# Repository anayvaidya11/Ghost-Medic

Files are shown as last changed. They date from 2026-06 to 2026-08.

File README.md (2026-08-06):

# Archiater

*A **Wyzantium Industries** project. Formerly Ghost Medic; renamed 2026-08-05.*

**Offline decision-support software for the trained responder, running on the
device they already carry, with an optional wrist sensor accessory streaming
raw signals into it.** A local language model reasons about the patient, the
environment, and what the responder says, and speaks numbered candidate
actions. The responder on scene decides. No network, ever.

It is built for the places where help is hours away and there is no signal —
which is precisely where every other assistant stops working, because they all
assume a network. The gap it aims at sits between a satellite messenger, which
can reach help but cannot tell you what to do, and a printed
wilderness-medicine manual, which knows what to do but cannot see your
situation. (Why the product is software-first, and what that decision killed:
[`docs/POSITIONING.md`](docs/POSITIONING.md).)

The full system: 

```
  ┌───────────────────────┐                 ┌─────────────────────────────────┐
  │  1. WRIST SENSOR      │    JSON over    │  2. END-USER DEVICE             │
  │  ACCESSORY (optional) │ ── USB serial ─▶│  the responder's phone / laptop │──▶ responder
  │  RP2040 hub,          │   (raw signal + │  local LLM + voice + screen app │    decides
  │  3 sensors            │    environment) │  (React Native / Expo, Ollama)  │
  └───────────────────────┘                 └─────────────────────────────────┘
     firmware/                                 services/ + app/ (this repo)
```

## The parts

### 1. Wrist sensor accessory — optional hub  → [`firmware/`](firmware/)
A **Raspberry Pi Pico / RP2040** reading three I²C sensors on a shared bus:

| Sensor | Role |
|---|---|
| MAX30102 | Raw optical (PPG) front-end — raw red/IR counts, **not** HR/SpO₂ |
| BMP280 | Barometric pressure → altitude |
| LIS3DH | Accelerometer → motion / fall detection |

It samples at 10 Hz and streams one JSON object per line over USB serial. The
firmware is bare-metal C written against the Raspberry Pi Pico SDK. See
[`firmware/README.md`](firmware/README.md) for the driver details and, importantly,
the **honest validation status** (summarized below).

>  The firmware is **written and
> compile-tested against the real Raspberry Pi Pico SDK** It has
> **NOT yet been flashed or run on physical hardware**, and its readings have not
> been checked against real sensors. The drivers were transcribed carefully from
> the MAX30102, BMP280, LIS3DH datasheets, but transcription and timing bugs can
> only be caught on a bench, which hasn't happened yet. Treat it as a
> compile-verified design artifact. Full detail and
> the reasoning (including why no simulator run) is in
> [`firmware/README.md`](firmware/README.md).

### 2. The end-user device — app + local LLM  → [`services/`](services/)
The responder's own phone, EUD, or laptop, running a **local, off-the-shelf**
language model that consumes the sensor stream plus the responder's input and
produces decision support — all offline.

**This works today** (verified 2026-07-22): the app sends its prompt plus a
sensor-context block to `llama3.2:3b` running under Ollama on the same machine,
and the sensor state measurably changes the guidance — a fall flag adds head,
neck and spine assessment that the same question without it does not produce.
Evidence: [`docs/session-reports/2026-07-22-phase2-sensor-aware-llm.md`](docs/session-reports/2026-07-22-phase2-sensor-aware-llm.md).

**No dedicated compute unit will be built.** The end-user device is the
compute (decision 2026-08-05, [`docs/POSITIONING.md`](docs/POSITIONING.md)).
A laptop stands in for that device in the demo — and a laptop *is* an
end-user device, which is the point.

### 3. Interface — voice + screen app  → repo root (this repo)
The **React Native / Expo** app is the voice and screen surface the user actually
interacts with. It lives directly at the repository root rather than in a single
subfolder:

| Path | What's there |
|---|---|
| [`app/`](app/) | expo-router app — entry (`_layout.tsx`) + the UI (`index.tsx`) |
| [`services/`](services/) | LLM plumbing + forward-looking sensor/vision stubs |
| [`training/`](training/) | Fine-tuning pipeline — see [`training/README.md`](training/README.md) |

## Start here (project docs)

| Doc | What it's for |
|---|---|
| [`ROADMAP.md`](ROADMAP.md) | **Read first.** Phased plan + what's done vs. next. |
| [`ARCHITECTURE.md`](ARCHITECTURE.md) | System topology, what runs where, real-vs-simulated table. |
| [`DATA_FORMAT.md`](DATA_FORMAT.md) | The NDJSON wire contract between firmware, bridge, and app. |
| [`docs/POSITIONING.md`](docs/POSITIONING.md) | Why the product was repositioned 2026-08-05. Read this to understand the current framing. |

## Repository layout

```
Archiater/
├── README.md            ← you are here (whole-system overview)
├── ROADMAP.md · ARCHITECTURE.md · DATA_FORMAT.md   ← project memory
├── firmware/            ← 1. wrist sensor accessory — RP2040 hub (Pico SDK C)
│   └── README.md          firmware detail + validation status
├── simulator/           ← browser demo emitting firmware-format JSON (hardware-free)
├── app/                 ← 3. interface — React Native / Expo app (the entry)
├── services/            ← LLM + sensor/vision service layer
├── training/            ← wilderness-medicine fine-tuning pipeline
├── legacy/              ← archived deterministic TCCC app (not the product)
├── app.json, package.json, tsconfig.json, babel.config.js
└── ...
```

The **product is the offline decision-support software** (`app/` + `services/`). An earlier
deterministic TCCC/MARCH engine lives in [`legacy/`](legacy/README.md) — archived,
not deleted, and not imported by anything shipping.

## Data flow, in one sentence

The wrist accessory emits JSON sensor lines over USB serial → a serial→WebSocket
bridge forwards them to the app → the app pairs them with the responder's voice
input and the local LLM's reasoning to give offline decision support.

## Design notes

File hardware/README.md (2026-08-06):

# Archiater — Wrist-Unit PCB (hardware/)

KiCad **10.0.4** design for the Archiater wrist-unit sensor hub — the custom
board referenced throughout the docs. This is the real design source, committed so
the "custom PCB" claim is backed by files you can open, not just a screenshot.

> ## ⚠️ Honest status
> This board is **designed and routed in KiCad — not fabricated, not assembled,
> and not bench-tested.** No copy of this PCB physically exists yet. The firmware
> (`../firmware/`) is separately compile-verified against the Pico SDK but has also
> **never been run on this board.** Treat this as a verified *design artifact*: a
> complete schematic + routed 2-layer layout, with pin assignments that match the
> firmware — not a manufactured product.

## What's here

| File | What it is |
|---|---|
| `archiater-sensor-hub.kicad_sch` | Schematic (source of truth for the wiring) |
| `archiater-sensor-hub.kicad_pcb` | Routed board layout (35 footprints, ~477 track segments) |
| `archiater-sensor-hub.kicad_pro` | KiCad project file |
| `exports/archiater-sensor-hub-schematic.pdf` | Schematic, exported for viewing without KiCad |
| `exports/archiater-sensor-hub-3d-top.png` | 3D board render (KiCad 3D viewer, top) — the still fallback on the website |
| `exports/archiater-sensor-hub.glb` | 3D board model for the website's interactive viewer |
| `exports/archiater-sensor-hub-front-copper.svg` | Front copper layer as 2D artwork |

The `exports/` images are **generated from the source in this folder** — see
"Regenerating the images" below. They are the design's own tool output, not photos:
no physical board exists to photograph (see status above).

## The design

A single-board wrist unit: an RP2040 reading three I²C sensors, powered/programmed
over USB-C.

| Ref | Part | Role |
|---|---|---|
| U3 | RP2040 | MCU (bare-metal firmware, `../firmware/`) |
| U1 | W25Q128JVS | QSPI flash (firmware storage) |
| U2 | AMS1117-3.3 | 5 V (USB VBUS) → 3.3 V regulator |
| U4 | MAX30102 | **Raw optical (PPG) front-end — raw red/IR counts, not HR/SpO₂** |
| U6 | BMP280 | Barometric pressure / temperature → altitude |
| U5 | LIS3DH | 3-axis accelerometer → motion / fall detection |
| J1 | USB-C 2.0 (16P) | Power + data |
| Y1 | 12 MHz crystal | RP2040 clock |
| R6, R7 | 4.7 kΩ | I²C SDA/SCL pull-ups (shared bus) |
| SW1, SW2 | Push buttons | RUN / BOOT |
| D1 | LED | Status |

The three sensors share **one I²C bus** with a single pull-up pair (R6/R7) — the
same shared-bus topology described in `../README.md` and `../DATA_FORMAT.md`. The
MAX30102 label here matches the rest of the repo: it is a **raw optical front-end**,
and the firmware exposes raw red/IR counts, **not** a computed heart rate or SpO₂.

## Regenerating the exports

Everything in `exports/` is reproducible from the source in this folder with
KiCad 10.x. `kicad-cli` ships inside KiCad — on macOS it lives at
`/Applications/KiCad/KiCad.app/Contents/MacOS/kicad-cli`, which is not on `PATH`
by default:

```sh
KC=/Applications/KiCad/KiCad.app/Contents/MacOS/kicad-cli

# 1 — schematic PDF
$KC sch export pdf archiater-sensor-hub.kicad_sch \
  -o exports/archiater-sensor-hub-schematic.pdf

# 2 — still 3D render (the website's fallback when WebGL is unavailable)
$KC pcb render archiater-sensor-hub.kicad_pcb \
  -o exports/archiater-sensor-hub-3d-top.png --side top --quality high

# 3 — 3D model for the website's interactive viewer
$KC pcb export glb archiater-sensor-hub.kicad_pcb \
  -o exports/archiater-sensor-hub.glb --force \
  --include-silkscreen --include-soldermask

# 4 — front copper as 2D artwork (black on transparent)
$KC pcb export svg archiater-sensor-hub.kicad_pcb \
  -o exports/archiater-sensor-hub-front-copper.svg \
  --layers F.Cu,Edge.Cuts --mode-single --exclude-drawing-sheet \
  --fit-page-to-board --black-and-white
```

Then copy the four outputs into `../site/assets/`.

Or open `archiater-sensor-hub.kicad_pro` in KiCad and use **View → 3D Viewer**.

### Notes on those choices, so they aren't silently re-litigated

- **GLB, not VRML or STEP.** `kicad-cli` can emit all three; GLB is binary glTF,
  which three.js loads natively via `GLTFLoader` with materials intact and no
  conversion step.
- **Silkscreen and soldermask only — no `--include-tracks/-pads/-zones`.** Adding
  those triples the file (1.8 MB → 6.1 MB) and quadruples the draw calls for
  geometry you cannot see: the soldermask renders opaque, so the copper is hidden
  in the 3D view exactly as it is on a real board. Export 4 above is how the
  routing is actually shown.
- **One model is missing.** The MAX30102's package (`Maxim_OLGA-14_3.3x5.6mm_P0.8mm`)
  has no STEP model in the standard library, so U4 has no body in the render and
  `kicad-cli` prints `File not found:` for it. The part is present in the
  schematic and routed on the board; only its 3D shape is absent. The website
  says so rather than substituting a stand-in shape.

## Where this sits in the project

Hardware is **not** on the current critical path — see `../ROADMAP.md` (the wired
bridge stands in for the board today, and PCB *fabrication* is explicitly deferred).
This folder exists so the design work is visible and verifiable now.

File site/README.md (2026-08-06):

# Archiater proof website (`site/`)

A **static site with no build step**: five hand-written HTML pages, one shared
stylesheet, and one vendored library. Nothing to install, nothing to compile.
This follows [`../docs/WEBSITE_STRATEGY.md`](../docs/WEBSITE_STRATEGY.md) §5
(static-first, boring, maintainable) rather than a framework.

**Audience:** startup founders. Technical enough to smell exaggeration, often
not embedded engineers. So the prose translates rather than simplifies: it keeps
the specific number and the engineering reason and drops the jargon. Status is
stated on the overview page before anything is demonstrated, because saying it
first is what makes the rest believable.

**House style:** no em dashes and no figurative language in any prose, title, or
caption. Short, direct sentences. Verbatim artifacts (test output, model
transcripts, code, the sensor block) are exempt and must never be edited to fit
the style, because their whole value is being unedited.

## What's in here

| Path | What it is |
|---|---|
| `index.html` | **Overview**, the pitch, the honest status ledger, the concept viewer, the wire format explained |
| `how-it-works.html` | **How it works**, the four stages in plain language, with an animated 2D pipeline diagram |
| `hardware.html` | **Hardware**, the 3D board viewer, the copper routing, why each part is there |
| `proof.html` | **Proof**, test output, the recorded model transcript, the real-vs-simulated table |
| `about.html` | **About**, who built it, with links |
| `style.css` | The whole design system. Two devices carry the site: the *translation pair* (`.translate`) and the *ledger mark* (`.mark`) |
| `assets/board-viewer.js` | three.js board viewer, merges draw calls, falls back to the static render on any failure |
| `assets/product-viewer.js` | three.js concept illustration of how the system would be worn. Placeholder shapes built in code, labelled as concept, falls back to the inline 2D SVG. Two views: on the body, and the units alone |
| `assets/wearer-figure.js` | The cropped body form the concept is worn on. Also built in code: a lofted torso and a swept arm, not a scan and not CAD |
| `assets/app-demo.js` | Scripted replay of the app's screen. The response text is the verbatim recorded run; no model runs in the page |
| `assets/charts/*.svg` | Chart plates generated from the shipping code. See `../tools/charts/README.md` |
| `assets/*.glb / *.svg / *.png / *.pdf` | Generated from `../hardware/` source, see below |
| `vendor/three/` | three.js r185, MIT, vendored so the site has **zero external requests** |

Every factual claim on the site maps to a file in this repository, and the site
links out to each one.

## Regenerating the hardware assets

All four come from the committed KiCad source. `kicad-cli` ships inside KiCad
(on macOS: `/Applications/KiCad/KiCad.app/Contents/MacOS/kicad-cli`). Exact
commands live in [`../hardware/README.md`](../hardware/README.md); copy the
outputs here afterwards:

```sh
cp ../hardware/exports/archiater-sensor-hub.glb                assets/
cp ../hardware/exports/archiater-sensor-hub-front-copper.svg   assets/
cp ../hardware/exports/archiater-sensor-hub-3d-top.png         assets/
cp ../hardware/exports/archiater-sensor-hub-schematic.pdf      assets/
```

## Regenerating the charts

The three SVGs in `assets/charts/` are drawn from data produced by the shipping
C and TypeScript. Commands in [`../tools/charts/README.md`](../tools/charts/README.md).

## The stylesheet version query

Pages link `style.css?v=N`. Bump `N` whenever `style.css` changes, so cached
copies don't serve a stale design.

## Preview locally

```sh
cd site
python3 -m http.server 8090
# open http://localhost:8090
```

Use the local server, not a double-click. Opening `index.html` from `file://`
blocks JavaScript modules, so both 3D viewers fall back to their still image and
2D diagram. That is the fallback working as designed, but it is not a faithful
preview.

To iterate on the concept viewer on its own, serve the repository root instead
and open `tools/render/preview.html`. It mounts the same module with the camera
the site ships, and prints the measurements under the canvas.

## Deploy to Vercel, exact steps (no experience assumed)

1. Go to <https://vercel.com> → **Sign Up** → **Continue with GitHub** (the
   account that owns `Archiater`). The free "Hobby" plan is fine.
2. **Add New…** (top right) → **Project**.
3. Under "Import Git Repository," find **Archiater** → **Import**. (If it
   isn't listed, click "Adjust GitHub App Permissions" and grant access.)
4. On the configure screen, change exactly three things:
   - **Root Directory** → **Edit** → choose the **`site`** folder.
   - **Framework Preset** → **Other**.
   - **Build Command** → leave **empty**. **Output Directory** → leave as **`.`**.
5. **Deploy**. Under a minute later you get a URL like
   `archiater-xxxx.vercel.app`.
6. Every future `git push` to `main` redeploys automatically.

Custom domain later: Project → **Settings → Domains**.

## Updating the site

Edit the HTML, commit, push. That's the entire pipeline. The one rule worth
keeping: **if a claim can't be traced to a file in this repo, it doesn't go on
the site.**

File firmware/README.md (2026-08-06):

# Archiater — Sensor Hub Firmware (RP2040 / Raspberry Pi Pico)

Bare-metal C firmware for a Raspberry Pi Pico that reads three I²C sensors and
streams their data as JSON lines over USB serial. Part of the **Archiater**
project — an offline-first wilderness survival assistant. This firmware is the
"sensor hub" data source: it produces the biodata/environment stream that a
downstream host (and ultimately a local LLM) consumes.

## ⚠️ Validation status — read this first

This is a **portfolio / design artifact**. Be clear on exactly what has and has
not been verified:

| Claim | Status |
|---|---|
| Compiles against the real Raspberry Pi Pico SDK (C, `hardware/i2c.h`) | ✅ **Verified** — builds clean |
| Builds with **zero warnings** under `-Wall -Wextra` at `-O3` | ✅ **Verified** |
| Produces a flashable UF2 (`ghost_medic_firmware.uf2`, committed) | ✅ **Verified** (valid UF2 output) |

> **Why the committed file keeps its old name.** The tracked
> `ghost_medic_firmware.uf2` is the artifact of the verified build made under
> the project's former name, Ghost Medic. The rename touched no C source that
> reaches the chip, but no Pico SDK toolchain is available on this machine, so
> rebuilding is not possible and renaming the file in place would manufacture
> evidence of a build that never happened. The renamed target will produce
> `archiater_firmware.uf2` at the next real build, and this file will be
> replaced then.
| Drivers written directly against the MAX30102 / BMP280 / LIS3DH datasheets | ✅ True |
| **Flashed and run on physical hardware** | ❌ **NOT done** |
| **Verified against real sensors** (correct readings, timing, FIFO behavior) | ❌ **NOT done** |
| Run in the Wokwi RP2040 simulator | ❌ Not done — see below |

**In plain terms:** the code is proven to be well-formed, idiomatic Pico SDK C
that the compiler and linker accept and turn into a real firmware image. It is
**not** proven to behave correctly on a bench. Register addresses, config bit
patterns, and the Bosch compensation math were transcribed carefully from the
datasheets, but transcription errors, timing issues, and datasheet
misreadings can only be caught with hardware (a Pico + the three breakout
modules), which has not yet been done. Nothing here should be read as
hardware-validated.

### Why no Wokwi run?

The plan allowed ~30 minutes attempting a Wokwi RP2040 C-SDK simulation. This
was **not pursued**, for an honest reason: Wokwi's RP2040 sim does not cleanly
model these three specific parts (the MAX30102 optical front-end, the BMP280's
per-chip NVM calibration block, and the LIS3DH). Wiring up custom chip stubs
would have been simulator-plumbing work that validates the *stub*, not the
*driver* — it would produce a green checkmark that means nothing. The compile
verification above is a more truthful signal than a faked-sensor sim would be.
The right next validation step is real hardware, not a simulator.

## What it does

On boot it initializes I²C and all three sensors, then loops at 10 Hz. Each
tick it reads every sensor and prints one JSON object per line over USB serial,
for example:

```json
{"t_ms":1234,"max30102":{"ok":true,"red":10342,"ir":10501},"bmp280":{"ok":true,"temp_c":22.5,"press_pa":101010.2,"alt_m":25.7},"lis3dh":{"ok":true,"x_g":0.01,"y_g":-0.02,"z_g":0.99,"mag_g":0.99},"fall_detected":false}
```

If a sensor fails to initialize, the loop still runs and that sensor's object
reports `"ok":false` — one dead sensor doesn't take down the stream.

## Sensors

| Sensor | Role | I²C addr | Notes |
|---|---|---|---|
| MAX30102 | Raw optical (PPG) front-end  | `0x57` | Fixed address. Driver reads **raw RED/IR FIFO counts only** — no HR/SpO₂ algorithm (out of scope). |
| BMP280 | Barometric pressure → altitude | `0x76` | SDO→GND. Reads factory calibration, applies Bosch compensation formulas. |
| LIS3DH | Accelerometer / fall detection | `0x18` | SDO→GND. Includes an **illustrative** free-fall→impact heuristic (see below). |

Pin assignment (SDA = GPIO4, SCL = GPIO5) intentionally matches the custom
Archiater PCB so breadboard and board firmware are identical.

### Note on fall detection

`lis3dh_update_fall_detection()` implements the commonly-taught two-phase
pattern: a free-fall dip (total acceleration ≈ 0 g) followed within a short
window by a high-g impact spike. **It is a demonstration heuristic with
untuned textbook thresholds, not a validated or medical-grade algorithm.** A
real detector would use windowed signal features validated against labelled
fall data. It's included to show the data being *used*, and is labelled as
illustrative in the source.

### Note on altitude

Altitude uses the international barometric formula against a **fixed** sea-level
reference of 101325 Pa. Real absolute altitude needs the *local* sea-level
pressure (which drifts with weather), so treat the altitude figure as good for
*relative* changes, not survey-grade absolute elevation.

## I²C speed

The bus runs at **400 kHz (fast mode)**. All three parts support it, and short
breadboard wiring has no signal-integrity reason to run slower; the higher rate
leaves time headroom to service three devices inside each 100 ms tick. If long
or noisy wiring causes read failures, drop `I2C_BAUD` in `main.c` to `100000`.

## Files

```
i2c_helpers.h   Shared I²C read/write register helpers (Pico SDK wrappers)
max30102.c/.h   MAX30102 driver — raw RED/IR FIFO read
bmp280.c/.h     BMP280 driver — calibration + Bosch compensation + altitude
lis3dh.c/.h     LIS3DH driver — XYZ read + fall-detection heuristic
main.c          Bus + sensor init, 10 Hz read loop, JSON serial output
CMakeLists.txt  Standard Pico SDK build
```

Each driver exposes an `init()` and a `read()` returning a clean struct, and
keeps its register addresses and config constants named and commented against
the datasheet field they represent (not bare hex).

## Building

Requires the Raspberry Pi Pico SDK and an ARM cross toolchain
(`gcc-arm-none-eabi`, `cmake`). Copy `pico_sdk_import.cmake` from the SDK's
`external/` directory next to `CMakeLists.txt` (or set `PICO_SDK_PATH`).

```bash
mkdir build && cd build
cmake -DPICO_SDK_PATH=/path/to/pico-sdk ..
make
```

This produces `archiater_firmware.uf2` (the target was renamed 2026-08-05).
To flash: hold **BOOTSEL** while
plugging in the Pico, then drag the `.uf2` onto the `RPI-RP2` drive that
appears.

### Build environment this was verified in

- ARM GNU toolchain `arm-none-eabi-gcc` 13.2
- CMake 3.28
- Raspberry Pi Pico SDK (cloned from upstream `master`), TinyUSB submodule
- Target board: default `pico` (RP2040), stdio routed over USB CDC

Result: clean compile and link of all four source files, zero warnings under
`-Wall -Wextra`, valid UF2 generated.

## Consuming the output (downstream)

`stdio` is routed over **USB CDC serial** (not the UART pins). On a host, the
Pico appears as a serial device (`/dev/ttyACM0`, `/dev/tty.usbmodem…`, or a
`COM` port). Each line is a complete JSON object. In the Archiater system a
small serial→WebSocket bridge forwards these lines to the React Native app —
the wired stand-in for the eventual wrist→pack BLE link (the Pico has no radio).

## Known limitations / honest TODO

- Not run on hardware; no reading has been checked against a reference.
- MAX30102 reads one sample per tick rather than draining the full FIFO — fine
  for a demo stream, insufficient for real PPG signal processing.
- No HR/SpO₂ computation (raw counts only).
- Fall-detection thresholds are untuned placeholders.
- No I²C error recovery/retry beyond per-read `ok:false` reporting.
- Altitude uses a fixed sea-level reference.

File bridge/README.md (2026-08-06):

# Archiater — Sensor Bridge

> ## ⚠️ What this is, stated honestly
> This bridge is a **wired, local WebSocket stand-in for the eventual
> wrist→pack _BLE_ link.** It is **not** BLE. It is **not** wireless. Nothing in
> this folder has run on physical hardware. It exists so the rest of the system
> (simulator → app → LLM) can be built and demonstrated **today, hardware-free**,
> and so that swapping in a real flashed Pico later changes only the data
> *source*, not the app. Do not read "bridge" as "the radio link works."

## What it does

A **dumb pipe.** It reads NDJSON telemetry lines from a *source* and forwards
each line **unchanged** to every connected *consumer* (the app, or a test client)
over a WebSocket.

```
  producers                         BRIDGE (this program)                 consumers
  ─────────                         ─────────────────────                 ─────────
  simulator ──ws /sim-input──▶   ┌────────────────────────┐   ──ws /stream──▶  app
  file replay ──────────────▶    │  drop lines w/o "t_ms"  │   ──ws /stream──▶  test-client
  serial (later) ───────────▶    │  forward the rest AS-IS │
                                 └────────────────────────┘
```

The bridge performs exactly **one** transformation, per
[`../DATA_FORMAT.md`](../DATA_FORMAT.md): it **drops any line that lacks a
`t_ms` field** (this silently drops the firmware's one-time boot line, and any
blank/garbage line). It does **not** parse-and-rebuild, reshape, or validate any
other field. Lines that pass the filter are forwarded byte-for-byte as received.

## Install

```sh
cd bridge
npm install        # installs 'ws' only
```

`serialport` is intentionally **not** a dependency yet — it will be added only
when `--source=serial` is actually implemented, to keep the dependency list
honest about what works.

## Run

**File mode** — replay captured lines at ~10 Hz (no browser, fully deterministic):

```sh
node bridge.js --source=file --file=sample.ndjson
```

**Sim mode** — accept live lines pushed by the browser simulator:

```sh
node bridge.js --source=sim
# then open ../simulator/index.html?bridge=1 in a browser and press Start
```

> The `?bridge=1` is required: the simulator only connects to the bridge when
> that flag is present. Opened plainly (no flag) it stays fully standalone and
> makes no network calls — so it never errors when the bridge isn't running.

**Serial mode** — reserved, not implemented:

```sh
node bridge.js --source=serial   # exits with a clear "not implemented" message
```

Options: `--port=8080` (default), `--hz=10` (file replay rate), `--loop`
(file mode only — replay the file from the top forever, for continuous app
testing without hardware; without it, file mode stops after one pass).

## Endpoints

| Path | Who connects | Direction |
|---|---|---|
| `ws://localhost:8080/stream` | the app / `test-client.js` | bridge → consumer (receive lines) |
| `ws://localhost:8080/sim-input` | the simulator | producer → bridge (push lines) |

## Test it (hardware-free)

Terminal 1:

```sh
node bridge.js --source=file --file=sample.ndjson
```

Terminal 2:

```sh
node test-client.js
```

`sample.ndjson` contains 5 non-empty lines: **1 boot line (no `t_ms`)** and
**4 data lines**. The test client should therefore receive **4** lines — proving
the boot line was dropped and everything else forwarded unchanged.

## Adding real hardware later (the seam)

`--source=serial` is stubbed on purpose. When a real Pico is flashed
(Phase 3 in [`../ROADMAP.md`](../ROADMAP.md)), implementing it means: open the
serial port, read newline-delimited lines, and call the **same** internal
`forward()` path that file and sim modes use. No consumer-side change, no
restructuring — that is the whole point of the producer/consumer split.

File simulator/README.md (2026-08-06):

# Archiater — Wrist Unit Simulator

A single-file, self-contained web page that **simulates** the Archiater wrist
sensor hub. Open `index.html` by double-clicking it — no server, no build step,
no internet, no dependencies.

## What this is (and is NOT)

- ✅ It **is** a demonstration of the Archiater data pipeline. You drag three
  sliders, physically-plausible sensor values are computed, and a live JSON
  stream scrolls past — the exact same JSON shape the real firmware prints.
- ❌ It is **NOT** reading any real hardware. There are no sensors attached.
  Nothing here talks to a Pico. The values are generated in your browser.

The page says this loudly in its header, on purpose. This is a simulator standing
in for the wrist unit.

## Why it's still faithful

Every formula and threshold in the simulator is copied straight from the real
firmware in this repo, so the numbers behave the way the actual device would:

| What | Simulator source | Firmware source |
|---|---|---|
| Altitude → barometric pressure | inverse of the barometric formula | `firmware/bmp280.c` (`SEA_LEVEL_PA`, exponent `0.1903`, coeff `44330`) |
| Temperature | 15 °C at sea level, −6.5 °C per 1000 m | standard-atmosphere lapse rate |
| Fall detection | free-fall < 0.35 g **then** impact > 2.5 g within 400 ms | `firmware/lis3dh.c` (`FREEFALL_THRESHOLD_G`, `IMPACT_THRESHOLD_G`, `FALL_IMPACT_WINDOW_MS`) |
| Raw IR/RED counts | large baseline integers + small pulsing waveform | `firmware/max30102.c` (raw 18-bit FIFO counts, **not** a real HR algorithm) |
| Loop rate | 10 Hz (one JSON line per 100 ms) | `firmware/main.c` (`LOOP_PERIOD_MS`) |

The **"Simulate Fall"** button scripts the real two-phase signature the firmware
looks for — a brief near-0 g free-fall dip followed by a high-g impact spike —
and runs the *same* detection code the RP2040 runs. When both phases land inside
the 400 ms window, the page raises a **FALL DETECTED** alert, exactly as the
firmware would flip `"fall_detected":true`.

## The JSON is the contract

The stream emits one object per line, matching the firmware byte-for-byte in
field order and number precision:

```json
{"t_ms":1234,"max30102":{"ok":true,"red":10342,"ir":10501},"bmp280":{"ok":true,"temp_c":22.5,"press_pa":101010.2,"alt_m":25.7},"lis3dh":{"ok":true,"x_g":0.01,"y_g":-0.02,"z_g":0.99,"mag_g":0.99},"fall_detected":false}
```

Because the shape is identical, **a real wired Pico can replace this simulated
source with zero downstream changes.** Anything that consumes the stream — the
app, an LLM, a serial→WebSocket bridge — cannot tell whether the line came from
this page or from a physical wrist unit. That's the whole point: prove and demo
the pipeline now, swap in real hardware later without touching the consumer side.

## How to open it

Double-click `simulator/index.html`, or drag it into any modern browser
(Chrome, Safari, Firefox, Edge). It runs entirely offline.

## Controls

- **Altitude (0–4000 m)** — sets BMP280 pressure and temperature.
- **Motion / g-force (0–4 g)** — drives the accelerometer magnitude.
  **Simulate Fall** scripts the free-fall→impact sequence.
- **Exertion (0–100)** — drives an internal pulse model that shapes the raw
  IR/RED optical counts. The pulse rate itself is never displayed or emitted —
  the device outputs raw counts, not heart rate.
- **Temp offset (−40..+20 °C)** — shifts the emitted BMP280 temperature on top
  of the altitude lapse rate (cold-snap / heat demos).
- **Sensor failures** — per-sensor checkboxes emit `{"ok":false}` with numeric
  fields omitted (per `DATA_FORMAT.md`), to exercise the consumer's failure path.
- **Pause / Clear** — freeze the stream or wipe the log.

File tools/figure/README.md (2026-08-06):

# tools/figure — where the mannequin comes from

`site/assets/wearer-body.glb`, the figure the product concept is worn on, is
built from MakeHuman's base mesh. This file records the source, the license,
and the exact commands, so the artifact maps to a documented pipeline the
same way the chart plates and the board GLB do. Nothing here ships with the
site and nothing is added to `package.json`; the two converters run under
`npx` on the dev machine only.

## Source and license

- **Source:** `base.obj` from the MakeHuman project,
  <https://raw.githubusercontent.com/makehumancommunity/makehuman/master/makehuman/data/3dobjs/base.obj>
  (retrieved 2026-08-05, 1,749,303 bytes, 19,158 vertices / 18,486 quads).
- **License: CC0 1.0.** Declared in the file's own header:

  > This asset was explicitly released as CC0 in september 2020. ...
  > The copyright holders at the point of the release to CC0 were:
  > Copyright (C) 2020 Data Collection AB, https://www.datacollection.se
  > Copyright (C) 2020 Joel Palmius
  > Copyright (C) 2020 Jonas Hauquier

  The MakeHuman application is GPL; its LICENSE materials state plainly that
  the license of exported assets is not affected. The mesh itself is CC0, so
  no attribution is required. Credit given anyway: the figure is the
  MakeHuman `hm08` base mesh.
- **What it is on the page:** a generic open-source base mesh rendered as a
  matte studio mannequin. It is not a scan of anyone and it is nobody's real
  proportions. The site says the same wherever the figure appears.

## The pipeline (run 2026-08-05)

```sh
curl -sLO https://raw.githubusercontent.com/makehumancommunity/makehuman/master/makehuman/data/3dobjs/base.obj

# 1 — keep only the `body` group. The source is one mesh in 172 groups:
#     the body, MakeHuman's helper-* clothing shells, and ~100 tiny joint-*
#     rigging cubes. Face indices are global, so the script renumbers them.
node tools/figure/extract-body.mjs base.obj body.obj
#   kept: body, 13,378 faces, 13,380 of 19,158 vertices referenced
#   dropped: 5,108 faces across 138 other groups

# 2 — OBJ to binary glTF
npx --yes obj2gltf@3 -i body.obj -o body-raw.glb --binary       # 452,280 B

# 3 — optimize for the web. Quantization only, no simplification: the full
#     13.4k quads keep the hands and face silhouette clean, and the file is
#     small anyway. KHR_mesh_quantization decodes natively in the vendored
#     three.js r185 GLTFLoader, so no decoder file has to ship.
npx --yes @gltf-transform/cli@4 optimize body-raw.glb wearer-body.glb \
  --compress quantize --simplify false --texture-compress false   # 268,640 B

cp wearer-body.glb ../site/assets/wearer-body.glb
```

A simplified variant (`--simplify true --simplify-ratio 0.6`) measured
161,616 bytes and was rejected: 107 KB was not worth the silhouette loss on
the one figure the page is about. For scale, the board GLB is 1.77 MB.

## Notes

- The source OBJ has no normals; the loader computes smooth vertex normals
  after merge (`site/assets/wearer-figure.js`).
- `--eyes` on the extract script also keeps MakeHuman's eyeball shells, in
  case the empty sockets read as holes in a render. The shipped build keeps
  only the body group; rebuild with `--eyes` if a render shows holes.

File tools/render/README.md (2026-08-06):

# tools/render — looking at the 3D concept viewer

Development tools. Nothing here ships with the site, and nothing here is a
project dependency: no entry is added to `package.json` and no package is
installed. `shot.mjs` talks to a browser that is already on the machine using
Node's built-in `WebSocket`.

## Why this exists

`site/assets/product-viewer.js` and `site/assets/wearer-figure.js` build their
geometry in code. Numbers can be checked headlessly, and are: the preview page
prints clearances, gaps and marker positions under the canvas. But a bounding box
cannot tell you whether an arm reads as an arm, so there has to be a way to
actually look at the thing while changing it.

The measurements are the point as much as the pictures. An early version of the
figure mounted the wrist band in a place that measured fine and looked wrong; a
later one had a cable that passed through the hand. Both were found by looking.
Both are now numbers the preview prints, so they cannot come back silently.

## preview.html

Mounts the same viewer module the site uses, on its own, with the camera the site
ships. Serve the **repository root**, not `site/`:

```sh
python3 -m http.server 8932
# then open:
#   http://localhost:8932/tools/render/preview.html            on the body
#   http://localhost:8932/tools/render/preview.html?wearer=0   the devices alone
```

`?devices=` picks the device set (`wrist+phone`, the shipped one, or the
harness-only `wrist+pack` / `wrist+phone+pack`). `?preset=` picks a camera
preset without clicking: `figure`, `wrist`, `phone`, `pack`, `all`.

The page never auto-rotates, so two screenshots of the same code are identical.

Printed under the canvas (the figure loads from a GLB, so the page waits for
the viewer's `ready` promise before measuring):

| Line | What it is guarding |
|---|---|
| `stature / scale applied / flipped` | The GLB's own units and facing are never trusted; this reports what normalisation actually did. The facing probe once flipped the figure backwards. |
| `wrist max radius` and `band radial margin` | The band's bore is sized to the measured wrist. A negative margin means the band is sunk into the skin. The wrist scan once landed in the palm and reported 45 mm. |
| `pack seat radius` | The (killed) pack's inner face is a 150 mm arc; the seat is wherever the measured torso curvature comes closest. |
| `chest surface z` | Where the chest mount's plate meets the measured torso. |
| `cable to torso gap` | Negative means the cable runs through the wearer. |
| `cable to arm gap` | Negative means the cable runs through the limb it is routed beside. It did once. |
| `cable slack` | A cable is longer than the gap it spans. Near 0% means it is drawn as a taut rod. |
| `marker N at` | Pixel position on the canvas, and the distance to the nearest other marker. Placing these by eye costs a screenshot per nudge. |

## shot.mjs

```sh
node shot.mjs <url> <out.png> [waitMs] [width] [height] [clipSelector] [clickSelector]
```

```sh
# the concept as the site renders it
node shot.mjs http://localhost:8932/tools/render/preview.html out.png 6500 1280 900 "#product-viewer"

# the site's own page, after clicking through to the other view
node shot.mjs http://localhost:8933/index.html out.png 5000 1280 900 "#product-viewer" 'button[data-view="units"]'
```

`waitMs` has to cover the WebGL scene settling; 5000 to 7000 is reliable with
software rendering. Page exceptions are printed to stderr, so a silent JavaScript
failure does not pass as a good screenshot.

Set `CHROME_PATH` if the browser is not in one of the usual places.

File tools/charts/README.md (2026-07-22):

# Chart pipeline (`tools/charts/`)

Generates the three chart plates in `site/assets/charts/`. The rule that makes
them trustworthy: **the data comes from the shipping code, and this folder only
draws it.**

| Output | Data source |
|---|---|
| `fall-signature.svg` | `trace_driver.c`, which links the firmware's own `fall_detection.c`. The motion trace is synthetic; every flag decision is the real state machine. |
| `altitude-curve.svg` | Same driver, sweeping `bmp280_pressure_to_altitude()` from the firmware's own `bmp280_compensation.c`. |
| `debounce.svg` | `debounce_data.mjs`, which imports the app's real `services/fallTrigger.ts` and replays 60 s of the demo fall loop: 2 calls instead of 150. |

The intermediate CSVs are committed so the SVGs can be checked against their
data without rebuilding anything.

## Regenerating

```sh
cd tools/charts

# 1. data from the shipping C
gcc -Wall -Wextra -std=c11 -I../../firmware trace_driver.c \
    ../../firmware/fall_detection.c ../../firmware/bmp280_compensation.c \
    -lm -o trace_driver && ./trace_driver

# 2. data from the shipping TypeScript (Node >= 22.6)
node --disable-warning=MODULE_TYPELESS_PACKAGE_JSON debounce_data.mjs

# 3. draw (any venv with matplotlib; not a project dependency)
python3 -m venv /tmp/chartsenv && /tmp/chartsenv/bin/pip install matplotlib
/tmp/chartsenv/bin/python make_charts.py
```

matplotlib is a build-time tool on the developer machine only. Nothing in the
site or the app depends on it; the site ships static SVGs with text as paths,
so they render identically with no fonts installed.

Style notes: single green data series (`#55884D`, validated for lightness,
chroma and contrast against the site's paper surface), gray reference lines,
clay reserved for the one status mark (the fall flag). Transparent background
so the plate sits on the site's paper panel.

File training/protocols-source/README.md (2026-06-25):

# Grounding Documents

Paste your source material here as plain-text (`.txt`) files. The dataset
generator (`../generateDataset.ts`) reads every `.txt` file in this folder and
folds the combined text into its prompts so synthetic answers stay anchored to
real doctrine rather than the model's unverified recall.

## What to put here

- **Wilderness Medical Society (WMS) practice guidelines** — e.g. the
  guidelines for hypothermia, frostbite, heat illness, acute altitude illness,
  anaphylaxis, lightning injuries, and spine assessment in the wilderness.
- **NOLS Wilderness Medicine** textbook excerpts — Patient Assessment System
  (PAS), the ABCDE primary survey, the SAMPLE secondary survey, and evacuation
  guidelines.
- **CDC wilderness / travel health references** — environmental exposure,
  waterborne illness, venomous bites and stings.

## Format guidance

- Plain UTF-8 text, one topic per file is fine (e.g. `wms-hypothermia.txt`).
- Strip page headers/footers and figure captions where you can — clean prose
  grounds the model better.
- Keep excerpts reasonably short; very long files are truncated by the
  generator to fit the prompt budget (see `MAX_GROUNDING_CHARS` in
  `../generateDataset.ts`).

## Copyright

These documents are used **locally** to ground synthetic data generation. Make
sure you have the right to use any copyrighted material this way, and do not
commit licensed text to a public repository. This folder is a drop point on your
own machine; only this README is tracked by default.

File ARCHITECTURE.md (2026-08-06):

# Archiater — Architecture

*What the system is, what runs where, and exactly where the "real" line is.*

Archiater (a **Wyzantium Industries** project, formerly Ghost Medic) is an
**offline decision-support prototype**: a trained responder — a medic, an
expedition leader, a remote-site lead — is treating a patient far from help,
with no signal. The system senses the patient and the environment, reasons
about it with a **local** language model, and speaks numbered candidate
actions for the responder to weigh — with **no internet**. The responder on
scene decides.

## The one product (decided 2026-07-20, repositioned 2026-08-05)

The product is **offline decision-support software running on the device the
responder already carries**, with the wrist sensor hub as an optional
accessory (`app/` + `services/`; rationale in
[`docs/POSITIONING.md`](docs/POSITIONING.md)). An earlier deterministic
TCCC/MARCH engine was archived to [`legacy/`](legacy/README.md); it is not
part of this architecture.

## System topology — what runs where

Three roles plus the human. In the **shipping vision** the end-user device is
the responder's own phone or EUD; in the **current demo** a laptop plays that
device. Being explicit about this is the whole point — it's how we stay honest
about what's proven.

```
 ┌────────────────────────┐            ┌─────────────────────────────────────┐
 │  WRIST SENSOR          │            │  END-USER DEVICE                    │
 │  ACCESSORY (optional)  │  THE LINK  │  (the phone / EUD / laptop the      │
 │                        │──────────▶ │   responder already carries)        │──▶ trained
 │  RP2040 + MAX30102 raw │  NDJSON    │                                     │    responder
 │  PPG + BMP280 baro +   │  over the  │  app (Expo) + local LLM (Ollama)    │    decides
 │  LIS3DH accel          │  bridge    │  + vision/voice stubs               │
 │  emits NDJSON @ 10 Hz  │            │  decision support, fully offline    │
 └────────────────────────┘            └─────────────────────────────────────┘

                    ══════════ THE BRIDGE ══════════
                    NDJSON source → WebSocket server
                    (stand-in for the eventual short-range wireless link)
```

### Role by role

| Role | Shipping vision | Demo today | Status |
|---|---|---|---|
| **Wrist sensor accessory** (optional) | Custom PCB: RP2040 + MAX30102 + BMP280 + LIS3DH | Same firmware, run on a Pico *or* replayed by the bridge | 🟢 Firmware built & compile-verified; ⚠️ not yet run on hardware |
| **The link** | Wrist → device short-range wireless (BLE) | Node WebSocket server, `--source ∈ {serial,sim,file}` | 🟢 Works in `file` mode (verified end-to-end); `serial` stubbed pending hardware |
| **End-user device** | The responder's phone / EUD, running the app and a local LLM | **Laptop** running the app in a browser and Ollama | 🟢 Works — and note the demo device *is* an end-user device, which is the point |

The pack-compute question is not deferred, it is **closed** (2026-08-05, see
[`docs/POSITIONING.md`](docs/POSITIONING.md)): the end-user device is the
compute. No dedicated carried computer will be chosen or built.

*The earlier four-role topology (with a dedicated "pack brain") is in git
history and analyzed in `docs/POSITIONING.md`.*

## Data flow (the contract-first design)

```
sensors → firmware → NDJSON line → bridge → WebSocket → app → LLM prompt → spoken advice
```

The load-bearing idea: **one JSON line format is the contract between every stage**
(see [`DATA_FORMAT.md`](DATA_FORMAT.md)). Because the shape is identical whether a
line came from a real Pico, the browser simulator, or a replayed capture, any
producer can be swapped for any other **without touching the consumer**. That is
what lets us prove the whole pipeline today, hardware-free, and swap in the real
wrist unit later by changing one flag.

## The three data sources (same format, increasing realism)

1. **`simulator/index.html`** — a browser page with sliders. A standalone *visual
   demo* you open yourself. Not in the app's data path, and **no longer embedded
   in the site** (removed from the overview page 25 Jul 2026, along with the
   byte-identical copy that used to live at `site/simulator/`).
2. **The bridge's `sim`/`file` modes** — replays/generates NDJSON at 10 Hz for the
   hardware-free app demo. The honest goal: generate it from the firmware's *own*
   pure C math (`firmware/bmp280_compensation.c`, `firmware/fall_detection.c`) so
   the test stream is the shipping code, not a reimplementation.
3. **A real flashed Pico** — `--source=serial`. The truth. Gated on hardware.

## What is real vs. simulated (read this honestly)

| Claim | Real? |
|---|---|
| Firmware compiles against the real Pico SDK, zero warnings, valid `.uf2` | ✅ Verified |
| Firmware sensor math (BMP280 compensation, fall detection) is unit-tested | ✅ Verified (host tests pass) |
| PCB designed & routed (RP2040 + 3 sensors, KiCad) — source in [`hardware/`](hardware/) | ✅ Real design (not fabricated/assembled) |
| Firmware run on physical hardware / real sensors | ❌ Not yet |
| App → local LLM → spoken numbered advice | ✅ Works (Ollama) |
| Live sensor data actually driving the app | ✅ Verified 2026-07-22 (bridge replay → browser app; connection observed server-side) |
| Sensor readings influencing the LLM's advice | ✅ Verified 2026-07-22 (sensor-context injection; fall auto-trigger fired once per 30 s cooldown against live local Ollama) |
| BLE wrist→device link | ❌ Simulated by the wired bridge (on purpose) |
| Speech-to-text, wound vision | ❌ Stubs (`services/transcriptionService.ts`, `services/visionService.ts`) |
| Runs on a dedicated carried computer | ❌ Killed by design (2026-08-05) — the end-user device is the compute; a laptop is the end-user device in the demo |

See [`ROADMAP.md`](ROADMAP.md) for the sequence that turns the 🔜/❌ rows green.

## Phase 2 — Sensor-Aware LLM  ✅ BUILT (2026-07-22)

*How live wrist telemetry reaches the model's reasoning. This section was written
as a design proposal and **is now implemented** — the design below was followed,
so it doubles as the module's documentation:*

- `services/sensorContext.ts` builds the delimited block (16 committed tests).
- `services/fallTrigger.ts` implements the rising-edge auto-trigger (12 tests).
- Both are wired into `app/index.tsx`; the exact block sent is viewable in the UI.
- Run the tests with `npm test` (39 total, no dependencies — see `tests/README.md`).
- Verified against live local Ollama: `docs/session-reports/2026-07-22-phase2-sensor-aware-llm.md`.

### Where it plugs in today
`services/llmService.ts` makes one call to Ollama `/api/generate` with:
- a **system** prompt (`WILDERNESS_SYSTEM_PROMPT`) — persona + wilderness-medicine
  doctrine (PAS / ABCDE / WMS), ≤6 one-sentence steps, mandatory EVACUATION line;
- a **user** prompt — `SITUATION REPORT:\n<patientReport>\n\nGive … steps now:`.

(Note: the app *simulates* token streaming — the model is called with
`stream:false` and the full text is replayed word-by-word. Real token streaming is
a separate later task.)

The snapshot already exists in the UI: `useWristVitals()` runs at the top of
`app/index.tsx`, so the latest `WristVitals` is in hand at submit time — **no new
plumbing needed to obtain it.**

### The injection point (simplest honest version)
Attach the **latest vitals snapshot at the moment of submit**, into the **user**
prompt (not the system prompt), as a clearly-fenced context block:

```
CURRENT SENSOR READINGS (wrist unit, live):
  Altitude: 2.1 m (relative)     Temperature: 21.0 °C (ambient)
  Fall detected: YES
  [raw signal — NOT vitals] optical red: 10249  ir: 10398   accel: 2.62 g
```

Rules that keep it honest:
- **Gate on `ok`.** Omit any field whose sensor reported `ok:false`; write
  `unavailable`, never a fabricated number or a `0`.
- **Label raw as raw.** Optical red/ir and accel magnitude are raw counts, passed
  through labeled "NOT vitals."
- **Forbid derivation the firmware didn't do.** The system prompt must explicitly
  instruct the model: *do not infer heart rate, SpO2, or pulse from the raw optical
  counts — that computation is not performed.* Without this, a model will happily
  invent a BPM. This is the load-bearing honesty guardrail of Phase 2.
- **Altitude is relative** (fixed 101325 Pa sea-level ref, per `DATA_FORMAT.md`) and
  temperature is **ambient**, not body temperature — say both in the block.

### System-prompt amendment (how to reason about the readings)
Add a short interpretation guide to `WILDERNESS_SYSTEM_PROMPT`:
- **Altitude** → weigh altitude-illness risk (AMS / HACE / HAPE) as elevation and
  ascent rate rise.
- **Temperature (ambient)** → near/below freezing raises hypothermia / frostbite
  risk; high temp raises heat-illness risk.
- **Fall detected = YES** → treat as possible fall trauma: spinal precaution,
  head- and internal-injury vigilance — weighed against the user's own report.
- **Raw optical / accel** → context only; explicitly *not* a vital sign.

### Trigger model
- **On user submit:** attach the current snapshot (above). Zero extra cadence.
- **On a fresh `fall_detected` rising edge (optional — the demo moment):**
  auto-compose a submit ("possible fall detected — <snapshot>") so a fall
  *visibly changes the advice* with no typing. This satisfies Phase 2's DONE-WHEN.
- A periodic "every N seconds" re-query is **not** proposed — it burns model calls,
  and the readings only matter at decision time.

### DONE WHEN (per ROADMAP)
A fall event or an abnormal vital *visibly changes* the model's guidance, with the
raw-vs-derived and "no HR/SpO2" labels intact in the injected context.

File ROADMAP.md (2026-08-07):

# Archiater — Roadmap

**Read this first, every session.** It exists so you never have to hold the whole
project in your head again. Pick the lowest unchecked phase, do it, check it off.

- **Product (decided 2026-07-20):** the **LLM wilderness assistant** (`app/` +
  `services/`). The old deterministic TCCC engine is archived in [`legacy/`](legacy/README.md).
- **What we're optimizing for:** *Goal B* — a highly technical, honest **proof**
  that the engineering works (simulation + real firmware link + docs), shown on a
  Vercel site + this repo. Not a hardware-validated medical device (that's Goal A,
  years away). For a proof, a **demonstrated, honestly-labeled** end-to-end pipeline
  beats a half-finished "real" one.
- **North star:** *one command brings up sensor stream (from the firmware's own
  math, no hardware) → bridge → app → local LLM → spoken triage advice, fully
  offline, every real-vs-simulated boundary labeled — plus one video of the Pico
  streaming on real hardware.*

See [`ARCHITECTURE.md`](ARCHITECTURE.md) for topology and [`DATA_FORMAT.md`](DATA_FORMAT.md)
for the wire contract.

---

## Locked Decisions (confirmed by owner — do not relitigate)

> **Repositioning 2026-08-05 (supersedes decision 1's framing; see
> [`docs/POSITIONING.md`](docs/POSITIONING.md)).** The product is **Archiater**
> (company: **Wyzantium Industries**): offline decision-support software for a
> trained responder, running on the device they already carry (phone / EUD /
> laptop), with the wrist sensor hub as an **optional accessory** streaming raw
> signals into it. The belt pack is killed, not deferred. The guidance posture
> is decision support, never directives to a layperson. Decision 1 below is
> kept as written because the history of the change is part of the record.

1. **What it is:** an offline, wearable AI **first-aid assistant prototype**. A
   wrist-worn sensor hub captures motion, altitude/environment, and raw optical
   signals, streams them to a **local (no-internet) LLM** that combines them with
   voice + image input to speak numbered first-aid guidance.
2. **What the app shows:** altitude, temperature, and fall-status as
   honestly-derived values; raw optical (red/IR) and acceleration as
   clearly-labeled **raw signal** (live trace). **No heart-rate / SpO2 / BPM number
   anywhere.** Raw vs. derived is visually distinguished.
3. **What the site proves:** a full offline pipeline (firmware-grade sensor data →
   bridge → app → local LLM → spoken advice) runs end-to-end and *responds to its
   inputs*, with every real-vs-simulated boundary labeled. The physical-hardware
   run is shown separately as a scoped video artifact.
4. **Build order:** Phase 1 bridge+app → Phase 2 sensor-changes-advice →
   Phase 3 hardware video → Phase 4 website.

### Out of scope (committed — do NOT build)
- No HR / SpO2 / BPM computation.
- No real BLE — the wired local WebSocket bridge is the honest stand-in.
- No dedicated "pack" hardware — **laptop = pack**; the topology is a documented
  tradeoff study, not a device to build now.
- No real speech-to-text or wound vision — both are **stubs**.
- No PCB fabrication.
- No medical-validity claims.

---

## Status legend
🟢 done · 🟡 in progress · ⬜ not started · 🧊 deferred (don't do yet)

---

## Phase 0 — Kill the ambiguity  🟢 DONE (2026-07-21)
*One product, one repo, shared memory.*
- 🟢 Decision made: product = LLM wilderness assistant.
- 🟢 TCCC engine archived to `legacy/` (product typechecks clean; nothing imports legacy).
- 🟢 `ARCHITECTURE.md`, `DATA_FORMAT.md`, this `ROADMAP.md` written.
- 🟢 `simulator/` committed.

## Phase 1 — The spine (the bridge)  🟡 IN PROGRESS
*Make sensor data actually reach the app. Highest leverage.*
- 🟢 Node bridge: reads NDJSON, re-broadcasts unchanged over `ws://localhost:8080`.
  `--source ∈ {serial, sim, file}`; `file` mode shipped (+ `--loop` for continuous
  replay), `serial` stubbed with a clear message. Drops lines without `t_ms`.
  Dep: `ws` only. Verified: `test-client.js` receives the 4 data lines, boot line
  dropped, loops correctly. (`bridge/`, spec in `DATA_FORMAT.md`.)
- 🟢 App wired to `ws://localhost:8080/stream`: `services/useWristVitals.ts` +
  `services/wristVitalsParser.ts` parse NDJSON per `DATA_FORMAT.md` (every field
  gated on its `ok` flag), consumed by `app/index.tsx`'s `VitalsMonitor` on the
  READY screen with a ●LIVE/○DISCONNECTED indicator. Honest: raw vs. derived split,
  nulls render "—", no HR/SpO2. Verified: `npx tsc --noEmit` clean; the compiled
  parser maps the live bridge stream to correct values (incl. `ok:false` → "—").
  *Not yet verified: React actually painting the values in a running browser.*
- ⬜ **Upgrade the `sim` source** to generate the stream from the firmware's *own*
  pure C (`firmware/bmp280_compensation.c`, `firmware/fall_detection.c`) compiled
  on the host — so the test data is the shipping code, not a reimplementation.
- **DONE WHEN:** replayed/generated sensor lines make the numbers in the app move, live.

## Phase 2 — Close the loop  🟡 NEARLY DONE (2026-07-22)
*Sensor data changes the AI's answer.*
- 🟢 Sensor context injection: `services/sensorContext.ts` (pure, 16/16 headless
  tests) builds a delimited block — derived values qualified (altitude relative,
  temp ambient-not-body), raw optical labeled non-diagnostic, `ok:false` →
  "unavailable" never 0, disconnected → honest "no sensor data". Appended to
  every LLM request in `app/index.tsx`; the exact sent block is viewable in the
  UI ("SENSOR CONTEXT ATTACHED" chip). System prompt extended with reasoning
  rules incl. NEVER inferring HR/SpO2 from raw counts.
- 🟢 Fall auto-trigger: `services/fallTrigger.ts` (rising edge + 30 s cooldown +
  suppression; 6/6 headless tests — 1 fire per replay loop, not 4). Auto-submits
  post-fall guidance, labeled "SENSOR-TRIGGERED (not typed by user)"; toggleable.
- 🟢 Simulator upgraded as demo instrument: temp-offset + per-sensor `ok:false`
  failure toggles (headless-verified against the app parser); bpm display
  removed (Decision 2).
- 🟢 **DONE-WHEN evidence:** real Ollama (llama3.2:3b, local) called with the
  app's exact payload construction — the fall-context response adds head/neck/
  spine + hidden-trauma assessment absent from the no-fall response; the model
  did not invent HR/SpO2 when probed. (Seeded proof harness; transcript in the
  2026-07-22 session report.)
- 🟢 **Tests committed 2026-07-22.** The 16/16 and 6/6 counts previously quoted
  here came from in-session harnesses that were never committed, so a reviewer
  who went looking found nothing. `tests/` now holds real files: 39 tests,
  `npm test`, no framework and no new dependency (node:test plus Node's native
  TypeScript support, Node >= 22.6). sensorContext 16, fallTrigger 12,
  wristVitalsParser 11.
- ⬜ Remaining: visually confirm the full loop in a running browser/app (same
  outstanding gap as Phase 1's "numbers move live" — everything up to the React
  render is verified headless). Known limit: the 3B model avoids inventing HR
  but doesn't always *state* it can't measure it, as the prompt instructs.

## Phase 3 — Hardware truth  ⬜ (gated on parts: a Pico + the 3 breakout sensors)
*The single highest-credibility artifact.*
- ⬜ Flash `firmware/ghost_medic_firmware.uf2`; capture a short **video** of the
  Pico streaming real JSON.
- ⬜ Run the same bridge with `--source=serial` against the real board.
- ⬜ Save a real capture file; note any datasheet/timing bugs found on the bench.
- **DONE WHEN:** one honest artifact proves the firmware runs on metal.

## Phase 4 — The proof website  🟡 BUILT, NOT YET DEPLOYED (2026-07-22)
*The honest storytelling layer over everything above.*
- 🟢 **Stack decision:** zero-dependency static site in `site/` (per
  `docs/WEBSITE_STRATEGY.md` §5 — static-first, no build step), NOT Next.js.
  Deploys to Vercel with root dir = `site`; exact owner steps in `site/README.md`.
- 🟢 Single scrolling page: topology → embedded live simulator (iframe, labeled)
  → physics section (real C excerpts + regenerated test receipts + interactive
  altitude formula widget, labeled as a JS mirror) → end-to-end section (recorded
  fall-vs-no-fall transcript, labeled "recorded, not live"; run-it-yourself
  commands) → firmware receipts → hardware page-section (KiCad render + designed-
  not-built gap box first) → annotated system prompt → full real-vs-simulated
  table. All self-contained, zero external resources.
- 🟢 Evidence record backing the site's transcript claims:
  `docs/session-reports/2026-07-22-phase2-sensor-aware-llm.md`.
- ⬜ Owner deploys to Vercel (steps in `site/README.md`) and eyeballs the page.
- ⬜ Hardware-run video slot stays honestly empty until Phase 3 happens.
- **DONE WHEN:** a stranger understands the engineering and sees it work in ~90 s.

### Phase 4b — rebuilt for a non-engineer audience  🟢 (2026-07-22)
*Same evidence, different reader. Target is a founder who is technical enough to
smell exaggeration but is not an embedded engineer.*
- 🟢 Split the single 530-line page into four: `index.html` (pitch, status,
  the wire format, the live simulator), `how-it-works.html`, `hardware.html`,
  `proof.html`. Shared `style.css`, shared nav, section anchors on every page.
- 🟢 Language rewritten throughout: translate rather than simplify, keeping the
  specific number and the engineering reason. Two structural devices carry it:
  the *translation pair* (technical artifact, then what it means) and the
  *ledger mark* (works today / standing in / simulated).
- 🟢 **House style, applies to all future site and doc prose:** no em dashes, no
  figurative language, short direct sentences. Verbatim artifacts (test output,
  model transcripts, code, the sensor block) are exempt and must never be edited
  to fit the style. Recorded in `site/README.md`.
- 🟢 3D board viewer: `kicad-cli pcb export glb` from the committed KiCad source,
  rendered with three.js r185 vendored into `site/vendor/` so the site still
  makes zero external requests. Falls back to the still render when WebGL is
  missing or the model fails to load; failure path tested by removing the file.
- 🟢 Front-copper 2D export added, because the soldermask hides the routing in 3D
  exactly as it would on a board.
- 🟢 Owner decision 2026-07-22: **the site says nothing about PCB fabrication
  status, either way.** Repo docs (`hardware/README.md`, `ARCHITECTURE.md`, this
  file) keep their accurate wording and the site links to them.
- 🟢 Honesty audit re-run: all links and asset references resolve, all quoted
  code and output checked against source, overclaim grep clean. It caught one
  real defect: the model transcripts had been condensed while being presented as
  recorded output. They are now verbatim.

### Phase 4c — product concept, charts, interface demo  🟢 (2026-07-22)
- 🟢 **3D product concept on the overview page** (owner-directed, overriding the
  earlier no-concept-renders rule): wrist unit (open tapered band, case with a
  display) wired to a curved belt pack. Placeholder shapes built in code, not
  CAD, labelled as concept on the page and in the source. Numbered markers map
  where the finished parts live; an inline 2D SVG is the no-WebGL fallback.
- 🟢 **The concept display is labelled concept-only** in the legend AND as a row
  in the Proof page's real-vs-simulated table: the built board has no screen.
- 🟢 The concept's cable is wired on purpose, captioned with `bridge/README.md`'s
  wording: a wired, local stand-in for the eventual wrist→pack BLE link.
- 🟢 **Three chart plates** (`site/assets/charts/`, pipeline in `tools/charts/`):
  fall signature and altitude curve computed by the firmware's own C, trigger
  debounce computed by the app's own `fallTrigger.ts` (2 calls vs 150). Data
  from shipping code; matplotlib only draws it (build-time tool on the dev
  machine, not a project dependency).
- 🟢 **Scripted interface demo** on How it works: a phone-frame replay of the
  fall auto-trigger showing the verbatim recorded response, labelled "no model
  is running in this page".
- 🟢 Layered desert-oasis background, prose tightened toward ~1 minute of text
  per page, and hand-designed-PCB authorship stated on Hardware and in the
  concept caption.
- 🟢 Concept refined: thicker cable, moulded pack (parting seam, recessed port,
  vents, softer fillets), larger display with a thinner bezel, softer shadow
  falloff. Callout 4 now names the compute class. `ARCHITECTURE.md` line 45 says
  "e.g. Jetson Orin Nano / Pi 5" and both docs defer the choice, and neither
  states a wattage, so the 7-15 W figure is attributed to that module class's own
  rating and the runtime is marked "on paper". The site says plainly that no
  module has been selected and nothing has been measured.
- 🟢 `site/about.html` added: who built it, two sentences, contact links.
- 🟢 Concept scale fix: the pack was rendering 136 mm wide (2.84x the case)
  because bendAroundY bent at the body radius, stretching the outer face 17%.
  Bending at the outer radius (175) preserves the documented 120 mm and lands
  the ratio at 2.45x, verified by measuring the rendered bounding boxes, not by
  eye. Belt strap rebuilt as a tapering swept arc at r=147.5 (behind the pack's
  150 mm inner face), symmetric ~27 mm past each side, lighter than the
  enclosure. Wrist and pack dimensions unchanged (48x40x11, 120x80x25).
- 🟢 Removed the concept LABEL box (folded the essential disclosure into the
  caption), the "dot is illustrative pacing" figcaption sentence, and the
  Hardware page's "criticism of my own layout" box (owner override). Hardware
  and Proof prose tightened further. About page renamed "About me".
- 🟢 Concept bend fix + more detail, and a hard site prose cut (2026-07-22).
  `bendAroundY` now uses each vertex's own radius (`theta = x / r`) instead of a
  single fixed radius. The fixed-radius version (this file's earlier note) held
  the outer face right but squeezed the inner face into a wedge: 92 mm against
  107 mm. The per-vertex bend renders 117 mm across, inner and outer within a
  millimetre, measured headless against the real `RoundedBoxGeometry`, not by
  eye. Cable deepened into a catenary (54% slack vs the straight span, clears
  the floor). Detail added: wrist side buttons (the board's real SW1/SW2, not a
  crown, which would imply an encoder the board lacks), an underside optical
  aperture (the MAX30102 window), strap lugs; pack recessed vent grille, a
  concept status LED, softer seam chamfer. **No browser render this session** —
  no Chromium is installed here, so the geometry is verified by measurement, not
  pixels. Site prose cut across all five pages (~3446 → ~2749 words, body prose
  excl. tables/chrome ~2637 → ~2027); every honesty disclosure and evidence link
  kept, overclaim grep and link check re-run clean.

### Phase 4d — the concept on a body, and a hard prose cut  🟢 (2026-07-25)
- 🟢 **A way to actually see the render.** Every earlier concept session shipped
  geometry verified only by measuring bounding boxes, because no browser was
  installed. `tools/render/` fixes that: `preview.html` mounts the viewer on its
  own with the camera the site ships, and `shot.mjs` screenshots it over the
  Chrome DevTools Protocol. **No new dependency** — Node's built-in `WebSocket`
  drives a Chromium already on the machine, and nothing is added to
  `package.json`. This paid for itself immediately (see the two defects below).
- 🟢 **`site/assets/wearer-figure.js`**: a cropped body form the concept is worn
  on. A torso lofted through superellipse cross-sections, an arm swept in one
  piece from shoulder to fingertip, and a belt that wraps the real surface. Built
  in code like the two units, and labelled on the page, in the module, and in the
  Proof table as a placeholder — not a scan, not CAD, nobody's proportions.
  Cropped deliberately: a whole standing figure puts the 48 mm case at about 3%
  of frame height and hides every detail on it.
- 🟢 **Placement is measured, not nudged.** The pack's inner face is a 150 mm arc
  and a waist is elliptical, so there is no angle where it sits flush. The code
  scans the front-left quadrant for the closest local radius of curvature and
  seats it there: **149.8 mm against 150.0**. The preview prints that, plus arm-to-
  torso gap (47.9 mm), shoulder burial (82.5 mm, which is what hides the cut end),
  cable-to-torso (24.0 mm), cable slack (18%) and every marker's pixel position.
- 🟢 **Two defects only a render could have caught.** The band mounted itself
  using the straight elbow-to-wrist chord rather than the curve's tangent, so it
  sat skewed across the base of the hand. And the cable ran from the connector
  straight at the belt, which on a raised arm means through the hand; it now
  leads back down the forearm first and clears by **9.3 mm**. *An initial
  diagnosis blamed centripetal Catmull-Rom spacing. That was wrong — three.js maps
  `t` uniformly across segments — and the comment in the file says so rather than
  keeping a tidy-sounding story.*
- 🟢 `product-viewer.js` refactored: wrist unit and belt pack extracted into their
  own builders, plus a `wearer` flag. The units-only view is **pixel-identical**
  to before, verified by screenshot against one taken before the refactor. Added
  `dispose()`, because the page now rebuilds the scene on every view switch and
  would otherwise leak a WebGL context each time.
- 🟢 Overview page carries both views behind a toggle, on-the-body first, which is
  what its heading ("What it would look like on you") was always promising.
- 🟢 **Cuts (owner-directed):** the embedded simulator and its section left the
  overview page, and `site/simulator/` (a byte-identical copy) is deleted along
  with the sync ritual in `site/README.md`. `ARCHITECTURE.md` §"three data
  sources" updated to say the simulator is standalone now. Hardware lost "Why each
  part is on the board" — the useful content moved into the parts table in plainer
  words. How it works lost the whole "03 · The pack computer" section; the
  numbered eyebrows went with it, since 01/02/04 reads as a mistake.
- 🟢 **Plain-language sweep** across all five pages: no "bare-metal", "downstream",
  "BLE", "LLM layer", "routing", "host tests", "prompt construction", "synthetic
  trace". Verbatim artifacts (test output, transcripts, code, the sensor block)
  untouched, per the house style. Link check clean over 50 local references,
  overclaim grep clean, `npm test` 39/39, `npx tsc --noEmit` clean.
- 🟢 **Proof page rebuilt around four pieces of evidence** (owner-directed): each
  is one trimmed code block followed by a plain "what this proves". The 39-line
  test wall is now 5 lines plus the pass count, the firmware output is the two
  Bosch comparison lines, and the two full model transcripts are one excerpt: the
  step that only exists in the fall run. Every cut is marked in grey inside the
  block and every full version is one link or one command away.
  **Watch this one.** A previous audit caught transcripts being condensed while
  presented as recorded output, so the excerpt is explicitly labelled and the
  session report is linked from beside it. Re-ran both suites to quote them
  honestly, and fixed a pre-existing defect while there: the firmware block had
  been re-spaced to fit the column, so the site was showing output that never
  came out of the terminal. `.receipt` scrolls horizontally, so it now carries
  the real spacing.
- 🟢 **Reading level is measured, not asserted.** `tools/prose/readability.mjs`
  scores each page (Flesch-Kincaid, target grade 10, skips `<pre>` and the shared
  nav/footer). All five pages pass: index 4.7, hardware 4.6, how-it-works 4.3,
  proof 4.7, about 9.4, whose only long sentence is a degree name. The first
  version of the script was wrong in an instructive way — with no sentence break
  at block tags it read the whole ledger table as one grade-72 sentence.
- ⬜ **Known gap:** `assets/charts/debounce.svg` still labels a line "the shipping
  trigger". Chart text is baked in as glyph paths, so fixing three words means
  installing matplotlib and regenerating all three plates, risking visual drift
  on the other two. The figcaption underneath translates it instead.

## Phase 5 — Reposition (Archiater)  🟡 IN PROGRESS (2026-08-05)
*The market said the form factor was wrong. The story changed; the pipeline did
not. Rationale and evidence: [`docs/POSITIONING.md`](docs/POSITIONING.md).*

- 🟢 `docs/POSITIONING.md` written: the harsh analysis (BATDOK/JOMIS incumbent,
  soldier load, FDA posture, unit economics), what survives, what was killed,
  honest limits stated flat.
- 🟢 Governing docs amended: `CLAUDE.md` (decision 1 rewritten, decision 5
  posture added), this file's superseding block, `ARCHITECTURE.md` three-box
  topology, `README.md` reframe. `DATA_FORMAT.md` needed zero changes.
- 🟢 App posture: system prompt addresses a trained responder ("the responder
  on scene decides"); `EVACUATION:` line format preserved for the parser;
  persistent "decision support, not a medical device" banner in the UI.
- 🟢 Rename Ghost Medic → **Archiater** / **Wyzantium Industries** across the
  repo (2026-08-05, six commit groups: prose docs, site, code identifiers,
  slugs+lockfiles, firmware guards+CMake target, KiCad sources+regenerated
  exports). The committed `ghost_medic_firmware.uf2` keeps its name: it is the
  artifact of the verified July build and renaming it would fake a build.
  Owner-gated leftovers: push + GitHub repo rename + Vercel project rename +
  working-directory rename.
- 🟢 On-body concept rebuilt to the new story (2026-08-05): a full standing
  mannequin from the MakeHuman CC0 base mesh (pipeline + license record in
  `tools/figure/`, 268 KB quantized GLB, no decoder needed), wrist accessory
  (concept display deleted: the board has no screen), chest-carried phone
  showing a mock of the real app layout, belt pack out of the shipped scene
  but still buildable in the render harness (`?devices=wrist+pack`). Mounts
  are measured off the loaded mesh, not eyeballed: the wrist is found by a
  minimum-girth slice scan, the band bore is sized to it, and the preview
  prints stature/flip/wrist-margin/cable-gap numbers. Four defects were
  caught by those numbers, not by eye: a backwards facing probe, a wrist scan
  that landed in the palm, and a cable through the torso and the arm.
- 🟢 Site visual redesign, the oasis (2026-08-06): scenery-only tokens (dune,
  pool, water, frond) with the rule written into the stylesheet that scenery
  never makes a claim; inline-SVG hero, dividers and footer waterline; paper
  grain from a committed build-time generator (`tools/render/grain.mjs`);
  depth shadows; the `--ink-3` contrast fix (2.9:1 to 5.2:1). Zero text
  nodes changed, proven by a byte-identical readability report. Text rewrite
  still deferred to its own session.
- 🟢 Round two, owner-directed (2026-08-06): the figure is male now (MakeHuman
  macrodetail morph applied by `tools/figure/apply-target.mjs`, same CC0
  pipeline); the phone rides a low belt at the hip pocket, where a hanging
  wrist ends up; the site viewer is two tabs only (On the body / Devices);
  the hero is a living canvas oasis (`site/assets/oasis.js`: layered dunes,
  palms that sway, a pool with reflection and rain rings, drifting sand, a
  passing shower every ~34 s; one still frame under reduced motion); the
  phone-compute claim is now verified fact with sources in
  `docs/POSITIONING.md` ("The phone is enough, verified"); and a fluff cut
  took body prose down again (index 491 to 395 words, how-it-works 602 to
  533, hardware 554 to 513, proof 885 to 802) with every honesty device
  kept. All gates re-run green.
- 🟢 Forest pass, owner-directed (2026-08-06): lush broadleaf trees frame the
  headline (pre-rendered leaf-blob sprites, swaying at the trunk), understory
  shrubs sink into the fade at the corners, and the rain is a constant soft
  drizzle that swells in waves instead of a rare shower.
- 🟢 The verge (2026-08-06): foliage down every page's margins, not just the
  hero. `site/assets/verge.js` mounts two fixed side strips where ferns,
  vines and leaf sprigs reach in from the edges, sway, drift against the
  scroll, and carry the same soft rain. Strips size themselves to the free
  margin beside the 58rem column and remove themselves when it is thin, so
  no line of text is ever crowded. `shot.mjs` gained a scrollY argument to
  photograph fixed layers mid-page.
- 🟢 Hip-carry defect, owner-caught (2026-08-06): in an A-pose the hands hang
  at hip height, their vertices leaked into the measured torso profile, and
  the inflated radii ballooned the belt and seated the phone on the hand
  instead of the hip. Fixed by excluding anything wider than the pelvis
  through that band of heights plus a circular median over each profile row;
  verified by preview screenshots, belt snug and phone flush.
- ⬜ **Next-session site worklist (text session):** investor-terse rewrite;
  hero spec strip using the four honest numbers — **0** external network
  requests · **10 Hz** one-line contract · **48** committed checks (39 app +
  9 firmware) · **77.5 × 71.75 mm** hand-routed 2-layer board; remaining
  claim-fixes listed in the 2026-08-05 session analysis.

## Deferred  🧊 (do NOT start these now — they're not on the critical path)
- 🧊 Run the fine-tune pipeline in `training/` (its existence is enough proof for now).
- 🧊 Real BLE wrist→pack link (the wired bridge is the honest stand-in).
- 🧊 Real speech-to-text (whisper.cpp) and wound vision — stubs are fine until
  Phase 2 works with text.
- ❌ ~~Choosing/building the dedicated "pack" compute device (Jetson/Pi 5)~~ —
  **KILLED 2026-08-05**, not deferred: the end-user device is the compute
  (`docs/POSITIONING.md`). A laptop stands in for the end-user device in the
  demo.
- 🧊 PCB fabrication (the design + firmware is the story).

---

## Anti-rathole rules
1. Never work on a 🧊 item while a ⬜ item below Phase 4 is open.
2. Every new claim on the website must map to a 🟢 row here.
3. When unsure "is this real or simulated?", the answer goes in the label, not the code.

## Known cleanups (small, do when convenient)
- ~~`services/llmConfig.example.ts` syntax error breaking typecheck~~ — **stale as
  of 2026-07-22**: `npx tsc --noEmit` passes clean; the file is 46 lines and fine.
- Consider lifting `legacy/src/scenarios/*.json` (wilderness vignettes) out for use
  as LLM demo/eval inputs.
- ~~If `simulator/index.html` changes, re-copy it to `site/simulator/index.html`~~
  — **gone as of 2026-07-25.** The site no longer embeds the simulator, and the
  copy under `site/` was deleted, so there is nothing left to keep in sync.

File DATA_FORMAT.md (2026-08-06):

# Archiater — Sensor Data Format (the contract)

This is the **wire contract** between the wrist unit (producer) and everything
downstream — the bridge, the app, the LLM. It is defined by the firmware in
[`firmware/main.c`](firmware/main.c); this document just writes it down so the
bridge and app can be built against it without reading C.

**If you change this format, change it in `firmware/main.c` first**, then here,
then the consumers. The firmware is the source of truth.

## Transport

- **NDJSON** — newline-delimited JSON. **One complete JSON object per line**, `\n`
  terminated. No pretty-printing, no multi-line objects.
- Emitted over **USB CDC serial** from a real Pico, at **10 Hz** (one line every
  ~100 ms; `LOOP_PERIOD_MS` in firmware).
- The bridge re-broadcasts each line **unchanged** over a WebSocket. It does not
  reshape, only forwards (and filters — see the boot line below).

## Two line types

### 1. Boot line (emitted once, at startup)

```json
{"boot":true,"max30102_init":true,"bmp280_init":true,"lis3dh_init":false}
```

- Printed once after init. Reports which sensors came up.
- **Has no `t_ms` field.** The bridge's rule — *drop any line without `t_ms`* —
  filters this out automatically, so consumers only ever see data lines. (Keep it
  in raw logs; it's useful for debugging a dead sensor.)

### 2. Data line (emitted every ~100 ms)

```json
{"t_ms":1234,"max30102":{"ok":true,"red":10342,"ir":10501},"bmp280":{"ok":true,"temp_c":22.5,"press_pa":101010.2,"alt_m":25.7},"lis3dh":{"ok":true,"x_g":0.01,"y_g":-0.02,"z_g":0.99,"mag_g":0.99},"fall_detected":false}
```

## Field reference

| Field | Type | Unit / meaning | Precision |
|---|---|---|---|
| `t_ms` | integer | milliseconds since boot (monotonic) | — |
| `max30102.ok` | bool | did this sensor read this tick | — |
| `max30102.red` | integer | raw RED optical FIFO count (18-bit range). **Raw counts, not HR.** | — |
| `max30102.ir` | integer | raw IR optical FIFO count | — |
| `bmp280.ok` | bool | — | — |
| `bmp280.temp_c` | float | temperature, °C | 2 dp |
| `bmp280.press_pa` | float | barometric pressure, pascals | 1 dp |
| `bmp280.alt_m` | float | altitude vs. fixed 101325 Pa sea-level ref. **Good for *relative* change, not survey-grade absolute.** | 1 dp |
| `lis3dh.ok` | bool | — | — |
| `lis3dh.x_g` / `y_g` / `z_g` | float | per-axis acceleration, g | 3 dp |
| `lis3dh.mag_g` | float | vector magnitude √(x²+y²+z²), g (~1.0 at rest) | 3 dp |
| `fall_detected` | bool | free-fall→impact signature seen. **Illustrative heuristic, not medical-grade.** | — |

**Producer invariant:** `fall_detected` is derived solely from the accelerometer,
so the firmware only computes it on a valid LIS3DH read (`firmware/main.c`). When
`lis3dh.ok` is `false`, `fall_detected` is always `false` — never a stale or
carried-over `true`. It is a top-level field rather than a member of the `lis3dh`
block because it is a *conclusion* about the readings, not a reading.

## ⚠️ The one parser gotcha: fields are OMITTED when a sensor fails

When a sensor's `ok` is `false`, its numeric fields are **not present at all**
(they are omitted, **not** set to `null` or `0`):

```json
{"t_ms":1500,"max30102":{"ok":false},"bmp280":{"ok":true,"temp_c":22.5,"press_pa":101010.2,"alt_m":25.7},"lis3dh":{"ok":true,"x_g":0.01,"y_g":-0.02,"z_g":0.99,"mag_g":0.99},"fall_detected":false}
```

Consumers must check `ok` before reading values, and treat missing fields as "no
reading this tick" — never as zero. One dead sensor must not take down the stream.

## Consumer checklist (app / bridge)

- Split the stream on `\n`; parse each line independently. A partial trailing line
  (no newline yet) must be buffered, not parsed.
- Ignore lines that don't parse as JSON, and lines without `t_ms`.
- Gate every numeric read behind its `ok` flag.
- Don't assume a fixed cadence for logic — use `t_ms` deltas (the 10 Hz is nominal).

## Reference lines for testing

```
{"boot":true,"max30102_init":true,"bmp280_init":true,"lis3dh_init":true}
{"t_ms":100,"max30102":{"ok":true,"red":10240,"ir":10390},"bmp280":{"ok":true,"temp_c":21.0,"press_pa":101325.0,"alt_m":0.0},"lis3dh":{"ok":true,"x_g":0.00,"y_g":0.00,"z_g":1.00,"mag_g":1.00},"fall_detected":false}
{"t_ms":200,"max30102":{"ok":true,"red":10251,"ir":10402},"bmp280":{"ok":true,"temp_c":21.0,"press_pa":101300.2,"alt_m":2.1},"lis3dh":{"ok":true,"x_g":0.02,"y_g":-0.01,"z_g":0.03,"mag_g":0.04},"fall_detected":false}
{"t_ms":300,"max30102":{"ok":true,"red":10249,"ir":10398},"bmp280":{"ok":true,"temp_c":21.0,"press_pa":101300.2,"alt_m":2.1},"lis3dh":{"ok":true,"x_g":1.80,"y_g":1.50,"z_g":1.20,"mag_g":2.62},"fall_detected":true}
```

(Line at `t_ms:200` shows near-0 g free-fall; `t_ms:300` shows the high-g impact
that flips `fall_detected` — the two-phase signature the firmware looks for.)

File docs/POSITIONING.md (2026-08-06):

# Positioning: why the product changed shape

**Decision date: 2026-08-05.** This document records a repositioning of the
product and the analysis behind it. It is the reference for every doc that
changed on that date.

## The decision, in five lines

1. The product is software first: offline decision support for a trained
   responder, running on the device that responder already carries.
2. The wrist sensor hub is an optional accessory, not the product. The routed
   PCB in `hardware/` is that accessory.
3. The belt pack is killed. Not deferred. Killed.
4. The guidance posture changes from spoken directives to decision support.
   The responder on scene decides.
5. New names: the product is **Archiater**, the company is **Wyzantium
   Industries**. The mechanical rename is a separate tracked workstream.

## What the market said

The United States military already fields point-of-injury software. It is
called BATDOK, built by the Air Force Research Laboratory. It runs on phones
the operator already carries. It works with no connectivity. It ingests
wireless sensors. The Joint Operational Medicine Information Systems program
selected it in 2022 as the point-of-injury and en-route care solution. It is
government owned and it adds zero grams to the load.

That last part matters most. Audited Marine combat loads average 117 pounds.
Army loads average 119. The Army's stated target is 55 pounds. Every new
device conversation with a program office starts with the question "what are
you removing." A dedicated wrist unit plus a dedicated belt computer, each
with its own battery, is a net addition. A 2018 Deputy Secretary of Defense
memo also restricts wearable devices in operational areas. Microsoft had ten
years and a contract ceiling of 22 billion dollars to make one body-worn
computer work, and IVAS still failed on ergonomics.

Civilian adjacencies point the same way. Expedition and remote-work markets
buy services, not boxes: a Garmin inReach subscription is a satellite link to
a human responder for about 30 dollars a month. Search and rescue teams are
volunteers with no equipment budget. NGOs buy standardized kits through
procurement centres. Nobody in these markets is waiting for another wearable.

## What the regulatory read said

Spoken, numbered treatment instructions delivered to an untrained person by a
model nobody can inspect is the single worst position in the FDA's software
framework. It fails the general wellness exemption, because trauma care is
treatment. It fails the clinical decision support carve-out, because that
carve-out requires the recommendation to go to a professional who can
independently review its basis. FDA guidance updated in January 2026 warns
specifically about automation bias and directive-style output from large
language models.

There is also a clinical evidence problem. A 2023 study in Prehospital and
Disaster Medicine prompted two commercial chatbots with the simplest possible
first-aid question, a person who is not breathing. Under ten percent of one
model's answers and about eleven percent of the other's fully matched
resuscitation guidelines. This project's own July 2026 test found the local
3B model avoids inventing vitals but does not always state its limits.

The defensible posture is the one this repo now takes. The software supports
a trained responder: a medic, an expedition leader, a remote-site lead. It
proposes candidate actions and states its reasons. The responder decides.
This is a positioning choice. It is not a claim of FDA clearance, compliance,
or clinical validation. No such claim is made anywhere in this repository,
and none may be added.

## What the unit economics said

A dedicated medical wearable at this niche's plausible volume sits below the
minimum order quantities at which contract manufacturing becomes rational.
The engineering cost never amortizes. There is no subscription to attach,
because offline operation means no service layer. And the model layer is
open weights and free. Anyone can ship it in an app. Several projects
already do. The scalable shape is software on hardware someone else already
bought, with optional hardware attached only where it earns its place.

## What survives the critique

- **The offline requirement is real.** Denied-communications environments
  exist, in conflict and in the backcountry. Cloud products structurally
  cannot serve them. This was always the honest core of the project.
- **The contract-first pipeline.** One JSON line is the only interface
  between firmware, bridge, and app. Any producer swaps for any other. This
  is why the repositioning cost nothing technically.
- **The routed PCB.** A real, hand-routed sensor board is a stronger artifact
  as an honest accessory than as the centerpiece of an unbuildable product.
- **The dual-use frame.** The same software serves a combat medic and an
  expedition leader. Both work far from help with no signal.

## The new product, exactly

Archiater is offline decision-support software for the trained responder,
running on the device they already carry: a phone, an end-user device, or a
laptop. An optional wrist sensor accessory, the existing PCB, streams raw
signals into it over one documented wire format. No network, ever.

```
 wrist sensor accessory (optional)  ──the link──▶  end-user device  ──▶  responder
 RP2040 + raw optical + baro + accel   NDJSON        app + local model      decides
```

The demo today runs the app in a browser and the model under local Ollama on
one laptop. A laptop is an end-user device. The demo has been the product
all along; the story around it was wrong.

## The phone is enough, verified

"A 3B-class model runs offline on a current phone" is a shipped fact, not a
research claim. Checked 2026-08-06 against primary sources:

- **Apple ships it.** Apple Intelligence includes an on-device foundation
  model of about 3 billion parameters, running on iPhone 15 Pro and later at
  about 30 tokens per second (Apple ML Research, "Introducing Apple's
  On-Device and Server Foundation Models").
- **Google ships it.** Gemini Nano runs on-device on Pixel 8 and 9 series
  and Galaxy S24 through the Android AICore service; Google's Gemma 3 1B
  runs at 529 MB via its AI Edge runtime (Google model cards and developer
  blog).
- **The open path this repo uses works too.** Meta publishes quantized
  Llama 3.2 1B and 3B for phones; measured decode is about 22 tokens per
  second for the 3B on an iPhone 16 Pro at roughly 2.8 GB peak RAM, against
  8 to 16 GB in current flagships. llama.cpp, MLC LLM, and Google AI Edge
  all run these models on Android and iOS today.
- **The honest limits.** Sustained generation throttles to roughly 40 to 65
  percent of burst speed as the phone heats; context windows on phone
  builds are short (2K to 8K tokens); and small models are dependable for
  extraction, summarization, and protocol lookup, not for open-ended
  clinical reasoning. All three limits fit this product's posture: short,
  retrieval-shaped decision support for a trained responder, in bursts.

The demo's llama3.2:3b under Ollama is the same model class Apple and Meta
run on phones. Nothing about the pipeline assumes more compute than a
responder already carries.

## What was killed, and why

| Killed | Reason |
|---|---|
| Belt pack | Adds carried load, cost, and a second battery. Duplicates the device already in the pocket. Was concept-only, so removing it falsifies nothing. |
| Dedicated compute selection | Was deferred. Now closed. The end-user device is the compute. |
| Directives to a layperson | Worst available regulatory quadrant, and the clinical evidence is against it. Replaced by responder decision support. |
| Wearable-first form factor | Competes with the government's own free, weightless software. The sensor hub survives as an optional accessory. |

## What the repo already proves about the new story

The repositioning changed no pipeline code. `DATA_FORMAT.md` is untouched.
The bridge, the firmware, the parser, the sensor-context builder, and all 39
committed tests are untouched. The system was software running on carried
hardware since the first commit. That the story could pivot without touching
the contract is evidence the contract-first design was correct.

## Honest limits

- No customers. No pilots. No letters of intent. No traction of any kind.
- No FDA interaction of any kind has occurred.
- Nothing is clinically validated. This is not a medical device.
- The firmware has never run on physical hardware.
- The PCB has never been fabricated.
- Speech-to-text and wound-photo analysis remain placeholder stubs.
- The one advantage claimed, offline operation, is also claimed by BATDOK,
  which is government owned and already fielded. The differentiators left
  are the open local-model reasoning layer and the labeled, auditable
  honesty of this pipeline. Whether those are enough is an open question,
  and this document does not pretend otherwise.

## What changed in this repo, and where

- `CLAUDE.md`: locked decision 1 rewritten, decision 5 added (posture).
- `ROADMAP.md`: superseding decision block, new Phase 5 section.
- `ARCHITECTURE.md`: three-box topology replaces the four-role diagram.
- `README.md`: reframed opening, diagram, and section 2.
- `services/llmService.ts`: system prompt now addresses a trained responder.
- `app/index.tsx`: tagline and a persistent decision-support banner.
- `DATA_FORMAT.md`, `bridge/`, `firmware/`, `hardware/`, `tests/`,
  `simulator/`: no changes.

## Key sources

BATDOK (AFRL): afresearchlab.com/technology/batdok. JOMIS selection reported
September 2023, thedefensepost.com. Soldier load: GAO-17-431. Wearables
restriction: Deputy Secretary of Defense memo, August 2018. FDA software
guidances: 21st Century Cures section 3060 CDS guidance and the January 2026
updates. Chatbot resuscitation study: Birkun and Gautam, Prehospital and
Disaster Medicine 38(6), 2023. IVAS: Breaking Defense, April 2025.
Phone inference: Apple ML Research, "Introducing Apple's On-Device and
Server Foundation Models"; Google AI Edge developer blog and the
gemma-3n-E2B model card; Meta, "Introducing quantized Llama models";
llama.cpp Android docs; MLC LLM docs. Checked 2026-08-06.

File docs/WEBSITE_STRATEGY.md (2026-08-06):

# Archiater — Website Strategy

*How to present an honest, unfinished hardware + software project online.*

**Audience:** you (solo, self-taught, no formal EE/CS). **Written:** 2026-07-21.
**Governing rule:** every claim on the site maps to real evidence in this repo.
Nothing faked, nothing overstated. The hardware has never been flashed to a real
device, and the site must say so plainly until that changes.

> **Jargon note:** the first time a technical term appears, it's explained in
> plain English right there. If a term shows up later without explanation, it was
> defined earlier — search the doc for it.

---

## 0. Evidence audit — read this before anything else

You can only present what you can prove. Here is the honest inventory of what's
actually in the repo today, and the one place the repo currently over-claims.

### ✅ Real and demonstrable (backed by files you can point to)

| Thing | Evidence in repo | What it proves |
|---|---|---|
| Firmware compiles to a real image | `firmware/build/ghost_medic_firmware.elf` **and** `.uf2` exist; `firmware/README.md` records a clean `-Wall -Wextra -O3` build | You can write bare-metal C that the Pico toolchain accepts |
| Sensor math is unit-tested | `firmware/tests/` (`test_bmp280.c`, `test_fall.c`) pass on a laptop; math matches Bosch datasheet reference (~25.08 °C, ~100653 Pa) | The formulas are correct, not just compiling |
| Testable architecture | `firmware/bmp280_compensation.{c,h}`, `firmware/fall_detection.{c,h}` — pure math split out from hardware I/O | You understand separation of concerns, a real professional pattern |
| One JSON wire format end-to-end | `DATA_FORMAT.md` + `firmware/main.c` + `simulator/` + `bridge/` all speak the same NDJSON | Contract-first design; sources are swappable |
| Interactive simulator | `simulator/index.html` — runs in a browser, uses the real firmware formulas | A visitor can *touch* the system with zero install |
| Working data bridge | `bridge/bridge.js` + `test-client.js` + `sample.ndjson`; simulator has opt-in `?bridge=1` output | Data actually flows source → bridge → consumer, live, today |
| Working app + real LLM prompt | `app/index.tsx` (voice / camera / text → response), `services/llmService.ts` with a real wilderness system prompt against Ollama | The software half genuinely works offline |
| Domain grounding | `services/llmService.ts` prompt (PAS, ABCDE, WMS), `training/` fine-tune pipeline, `legacy/src/scenarios/*.json` vignettes | You did real wilderness-medicine homework |

**Terms used above:**
- **Bare-metal C** — code that runs directly on the chip with no operating
  system underneath it.
- **`.uf2` / `.elf`** — the compiled firmware files. `.uf2` is the one you drag
  onto a Pico to flash it; `.elf` is the richer build output it's made from.
- **NDJSON** — "newline-delimited JSON": one complete JSON object per line. A
  dead-simple streaming format.
- **Ollama** — a program that runs a language model locally on your own machine,
  no internet needed.
- **PAS / ABCDE / WMS** — standard wilderness-medicine frameworks (Patient
  Assessment System; the Airway-Breathing-Circulation-Disability-Exposure check
  order; Wilderness Medical Society).

### ❌ Explicitly NOT done (and the repo already says so — keep it that way)

- Firmware **never flashed or run on a physical Pico**; no reading ever checked
  against a real sensor. (`firmware/README.md`, `ARCHITECTURE.md`.)
- **No BLE / wireless.** The bridge is a *wired* WebSocket stand-in for the
  eventual radio link. (`bridge/README.md` states this loudly.)
- **Speech-to-text and wound-vision are stubs** (`services/transcriptionService.ts`,
  `services/visionService.ts`).
- **No dedicated "pack brain" compute device** — a laptop stands in.

### ✅ RESOLVED (2026-07-21): the PCB design is now committed

**A PCB is a "printed circuit board" — the physical green board that parts get
soldered onto. "KiCad" is the free software used to design one (the schematic =
wiring diagram, and the board layout = physical placement of parts and copper
traces).**

*This used to be the biggest honesty risk on the site:* `ARCHITECTURE.md` claimed
a "PCB designed … ✅ Real design" but no KiCad files were in the repo. **That is
now fixed** — the real KiCad 10.x source (schematic + routed board + project file)
lives in [`../hardware/`](../hardware/), alongside an exported schematic PDF and a
3D render generated from that source. It resolves via option 1 below.

So on the site, the wrist unit can now use its **strongest** visual honestly (see
Part 2a): the KiCad 3D render + a schematic excerpt, backed by openable files.

**The claim that remains, and must stay labeled:** the board is **designed and
routed, NOT fabricated, assembled, or bench-tested** — no physical copy exists.
`hardware/README.md` and the `ARCHITECTURE.md` table both state this. Keep that
line wherever the board appears; "designed" must never quietly become "built."

---

## PART 1 — How unfinished physical products get presented online

A survey of the common patterns, each with: **what it is**, **what tools make
it**, **how much effort**, and **the honesty verdict for *your* situation** (no
physical hardware yet). I flag anything that would imply you have more than you do.

### Pattern A — Photorealistic 3D renders
**What:** computer-generated images that look like glossy product photos.
**Tools:** Blender (free), Fusion 360 (free tier), KeyShot (paid).
**Effort:** high for someone new — days to a convincing render.
**Honesty verdict for you:** ⚠️ **Handle with care.** A render that looks like a
photo of a finished product, with no label, is the closest thing to a lie on this
list — it implies the object exists. A render that is clearly *labeled as a
concept* and styled so it reads as CAD/concept (not a photo) is fine. The label
is what separates honest from dishonest. See Part 4 for the full treatment.

### Pattern B — CAD / KiCad screenshots (the honest cousin of renders)
**What:** screenshots straight from the design software — a schematic, a board
layout, or KiCad's built-in 3D board viewer.
**Tools:** KiCad (free) for the PCB; FreeCAD/Fusion for an enclosure.
**Effort:** low-to-medium *if the design already exists* (it's just a screenshot);
high if you have to create the design first.
**Honesty verdict:** ✅ **Ideal for you** — *if* the design exists (see the PCB
caveat above). A CAD screenshot inherently says "this is a design, not a
manufactured thing." Nobody mistakes a schematic for a product photo. This is the
single most honest way to show hardware-that-doesn't-physically-exist-yet.

### Pattern C — Real photographs
**What:** actual photos of actual hardware.
**Honesty verdict:** ❌ **Off the table for now** — you have no hardware to
photograph. The day you flash a real Pico on a breadboard, a genuine phone photo
of it (even ugly, even on a messy desk) becomes one of your *highest*-credibility
assets, precisely because it's obviously real. Plan for it (Phase 3 in your
`ROADMAP.md`), don't fake it.

### Pattern D — Interactive browser demos
**What:** something the visitor can click, drag, and watch respond — live, in the
page, no install.
**Tools:** plain HTML/CSS/JS (you already did this — `simulator/index.html`).
**Effort:** you've already paid it for the simulator.
**Honesty verdict:** ✅✅ **Your single strongest card.** An interactive demo
proves the logic works because the visitor *runs it themselves*. It can't be
faked the way a screenshot can. Your simulator already carries an explicit "this
is a SIMULATOR, not real hardware" banner — that honesty is exactly right and
makes the demo *more* credible, not less.

### Pattern E — Architecture / system diagrams
**What:** boxes-and-arrows showing how parts connect and where data flows.
**Tools:** Excalidraw (free, hand-drawn look), draw.io (free), Mermaid (diagrams
written as text, render in Markdown/most site frameworks), Figma.
**Effort:** low. Hours, not days.
**Honesty verdict:** ✅ **Do this early.** You already have the raw material as
ASCII diagrams in `README.md` and `ARCHITECTURE.md`, plus the real-vs-simulated
table (which is gold — most projects hide that line; you draw it). A diagram
claims nothing about physical existence, so there's no honesty risk, and it's how
a reviewer understands the system in 20 seconds.

### Pattern F — Video walkthroughs / screen recordings
**What:** a short screen (or phone) recording of the thing actually running.
**Tools:** QuickTime (Mac, built in) or OBS Studio (free) for screen capture;
your phone for the app; iMovie for trimming.
**Effort:** low-to-medium. The hard part is doing a clean take, not the tooling.
**Honesty verdict:** ✅ **Excellent, with correct captions.** A 30–60 second
recording of the simulator driving the bridge driving the app is real evidence.
Caption what the viewer is seeing ("simulated sensor data," "local LLM on a
laptop") and it's bulletproof. This is also your *fallback* for anything that's
too fragile to run live in a stranger's browser (see Part 3).

### Pattern G — Live telemetry dashboards
**What:** a page showing data updating in real time — moving numbers, a scrolling
log, little charts.
**Tools:** plain JS + a charting lib (uPlot or Chart.js, both free); your
`bridge` already emits the data over WebSocket.
**Effort:** medium.
**Honesty verdict:** ✅ with a label. Your simulator's scrolling JSON feed is
already a mini telemetry dashboard. A richer one is a nice-to-have, not a
priority — as long as it says the data is simulated.

### Pattern H — "How it works" explainer sections
**What:** prose + diagrams walking through the system for a non-expert.
**Effort:** low (you've basically written it already across your docs).
**Honesty verdict:** ✅ Always good. Your docs are unusually honest and
well-written; the website explainer is mostly an editing job on text that exists.

### Real-world examples to study (at your stage or adjacent)

These are durable, well-known references. I'm citing them from knowledge, not
live-fetching them today — click through and confirm each still matches before
you lean on it.

- **Oxide Computer (oxide.computer)** — a hardware company that built enormous
  credibility *through public honesty and documentation* (their RFD process,
  deep technical blog) long before most people could buy anything. The lesson
  isn't the polish; it's that transparency reads as competence.
- **Adafruit / Pimoroni product pages** — the gold standard for mixing **CAD
  renders + real photos + pinout diagrams + schematics** on one page. Study how
  they clearly distinguish a labeled pinout diagram from a product photo.
- **Prusa / RepRap build logs & bunnie Huang's blog (bunniestudios.com)** —
  long-form "here's the messy real engineering, including what broke" writing.
  This is the tone your `HONEST_REPORT`-style docs already have.
- **KiCad project write-ups on Hackaday.io and personal EE portfolios** — search
  "KiCad project portfolio" — you'll see the standard, honest visual vocabulary:
  schematic snippet → 2D board layout → KiCad 3D viewer render → (if built) a
  breadboard photo. Copy that exact ladder.
- **Teenage Engineering / Playdate (play.date)** — for *aesthetic* reference only:
  how a rugged/industrial product identity is carried through a whole site. Your
  simulator's tactical look is already in this family.

**The pattern across all the good ones:** they never blur the line between
"designed," "simulated," and "physically working." They *label the line and make
it a feature.* That is precisely your project's whole thesis (`ROADMAP.md` Goal
B). Lean into it.

---

## PART 2 — What Archiater has, and how to present each piece honestly
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

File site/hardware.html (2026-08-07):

Skip to content

Archiater

Hardware

# The wrist unit, routed down to the last trace.

One processor, three sensors, 35 parts, 477 tracks, one USB-C socket. Every part placed and every track laid by hand in KiCad. The files are in the repository.

The design in three dimensions

## Drag to turn it over

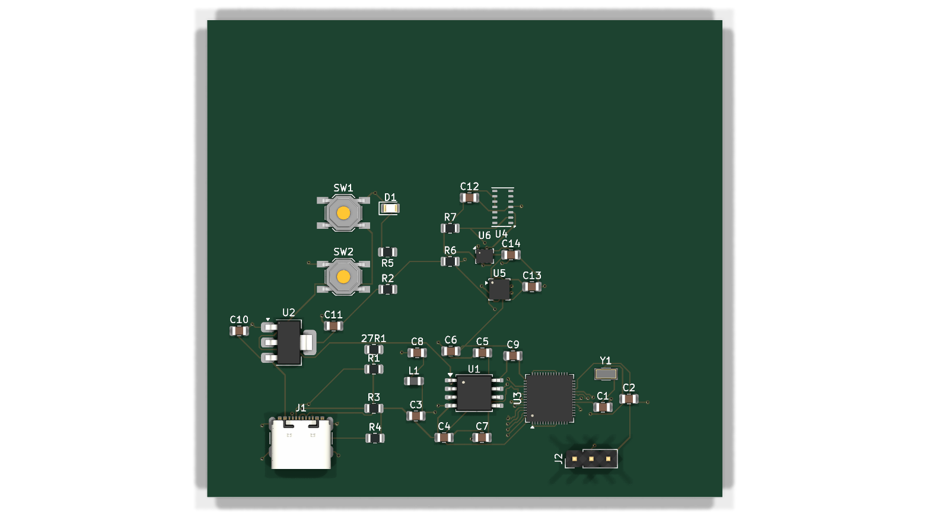
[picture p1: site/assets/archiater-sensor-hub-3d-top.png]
The Archiater sensor-hub circuit board, top view, generated by KiCad's 3D viewer from the layout file.


Reset view

Exported from the layout by KiCad itself, command in hardware/README.md (https://github.com/anayvaidya11/Archiater/blob/main/hardware/README.md). Drag to turn, scroll to zoom.

Two things this picture does not show

The light sensor is missing from it. Nobody has drawn a 3D shape for that part, so the exporter leaves its spot empty. It is in the circuit, in the layout and fully wired up. The hole is left visible rather than filled in with something invented.
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

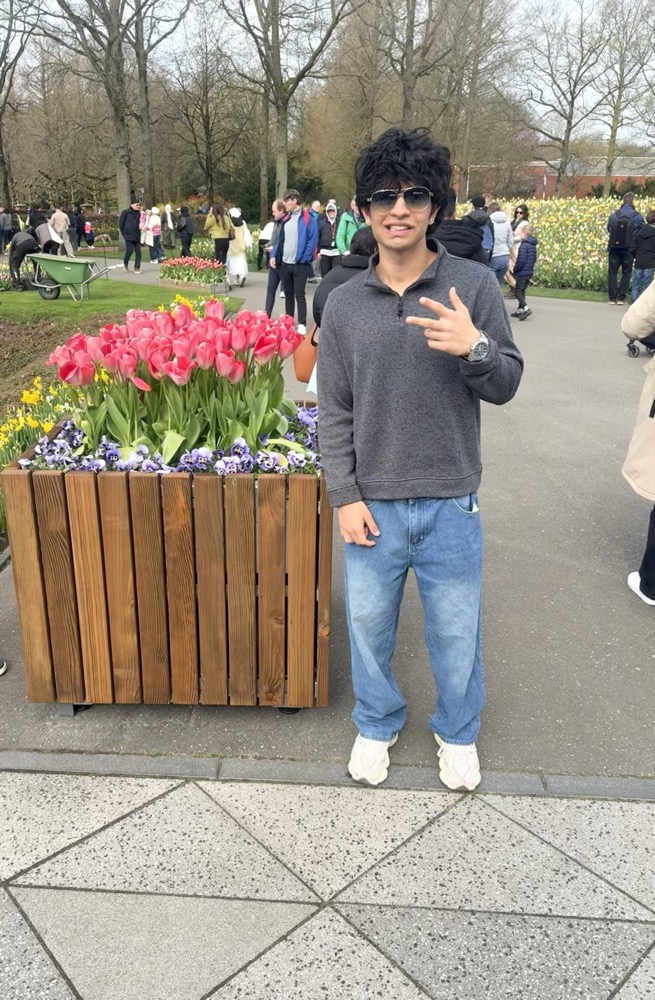
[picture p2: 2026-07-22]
site/assets/anay-vaidya.jpeg

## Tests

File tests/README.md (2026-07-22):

# Tests

Headless tests for the pure TypeScript modules — the ones that decide what the
language model is told about the sensors, and when it speaks up on its own.

```sh
npm test
```

**39 tests, no dependencies to install.** They use Node's built-in test runner
(`node:test`) and Node's built-in TypeScript support, so there is no framework,
no config, and no build step — the tests import the shipping `.ts` files
directly and run the same code the app runs.

| File | Module under test | Tests |
|---|---|---|
| `wristVitalsParser.test.mjs` | `services/wristVitalsParser.ts` — reads one line of wristband telemetry | 11 |
| `sensorContext.test.mjs` | `services/sensorContext.ts` — builds the sensor block sent to the model | 16 |
| `fallTrigger.test.mjs` | `services/fallTrigger.ts` — decides when a fall makes the app speak first | 12 |

**Requires Node 22.6 or newer** (Node's native TypeScript support). Node 24 is
what these were written and run against. On an older Node you will see a syntax
error on the first `import` of a `.ts` file — upgrade rather than adding a
transpiler.

## What these are actually guarding

Not coverage. Three specific ways this project could quietly start lying:

1. **A failed sensor becoming a number.** When a sensor drops out, its fields are
   *omitted* from the wire format (see `../DATA_FORMAT.md`) — not sent as zero.
   A parser that reads a missing field as `0` would print a confident, wrong
   reading at exactly the moment a sensor died, and the model would then reason
   about it. Several tests exist only to hold that line.

2. **Inventing vital signs.** The optical sensor produces raw light counts, and
   nothing in this project turns them into a heart rate. The tests assert both
   that the parsed data has no field to put one in, and that the text sent to the
   model always carries the instruction forbidding it.

3. **Asking the model forty questions about one stumble.** The wristband reports
   ten times a second and the demo replays on a loop, so a single fall produces a
   long run of identical "fall detected" readings. `fallTrigger` fires once per
   fall and then goes quiet; the tests replay the real sample capture to prove it.

The firmware's own C math has a separate, older suite — see `../firmware/tests/`.

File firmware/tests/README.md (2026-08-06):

# Archiater — host-side firmware tests

These are **unit tests for the sensor math**, and they run on your laptop with a
normal C compiler (`gcc`). **No Raspberry Pi Pico, no sensors, no wiring** are
needed to run them.

## How to run them

From this folder:

```sh
make
```

That compiles two small test programs and runs them. You'll see a `PASS`/`FAIL`
line for each check and a summary. `make` exits non-zero if anything fails.

To just build without running: `make build`. To clean up: `make clean`.

Under the hood each test is a plain C program with its own `main()`, compiled
with:

```
gcc -Wall -Wextra -std=c11 -I.. <the pure module>.c <the test>.c -lm
```

## Why this is possible without hardware (the design point)

The firmware was refactored so the **pure math** is separated from the
**hardware I/O**:

- `../bmp280_compensation.c` — the BMP280 temperature/pressure/altitude
  formulas. No I2C, no SDK headers.
- `../fall_detection.c` — the free-fall→impact fall-detection state machine.
  No I2C, no SDK headers.

The real drivers (`../bmp280.c`, `../lis3dh.c`) still do all the I2C reads and
byte-unpacking, then call these exact functions. Because the driver and the
tests call the **same** code, a passing test is real evidence about the code
that actually ships to the Pico — not a separate reimplementation.

## What these tests PROVE

- **BMP280:** the compensation formulas are transcribed correctly. We feed the
  Bosch datasheet worked-example calibration + raw ADC values and confirm we
  get ~25.08 °C and ~100653 Pa. We also sanity-check the altitude helper
  (sea-level pressure → ~0 m; ~89875 Pa → ~1000 m; lower pressure always reads
  as higher altitude).
- **Fall detection:** the logic flags a real fall (free-fall then impact within
  400 ms), and correctly ignores (a) a bare jolt with no preceding free-fall
  and (b) an impact that arrives after the 400 ms window has closed.

## What these tests do NOT prove

- That a real BMP280 or LIS3DH is wired up and responding.
- That a real sensor returns these particular raw values, or is calibrated as
  assumed.
- That the fall thresholds are well-tuned for an actual human wrist — they're
  reasonable textbook starting points, not values validated against labelled
  fall data.

**All of that still requires a bench test on a wired Pico.** These host tests
check the *math and logic*; they are a fast, hardware-free first line of
defense, not a substitute for real-hardware validation.

## A caveat on the BMP280 reference numbers

The calibration constants and expected outputs in `test_bmp280.c` are the
well-known BMP280 worked example. Before calling them "datasheet-verified,"
double-check them against your actual Bosch **BST-BMP280-DS001** datasheet PDF
(section 3.11.3 / 8.1). There's a comment in the test saying exactly this.

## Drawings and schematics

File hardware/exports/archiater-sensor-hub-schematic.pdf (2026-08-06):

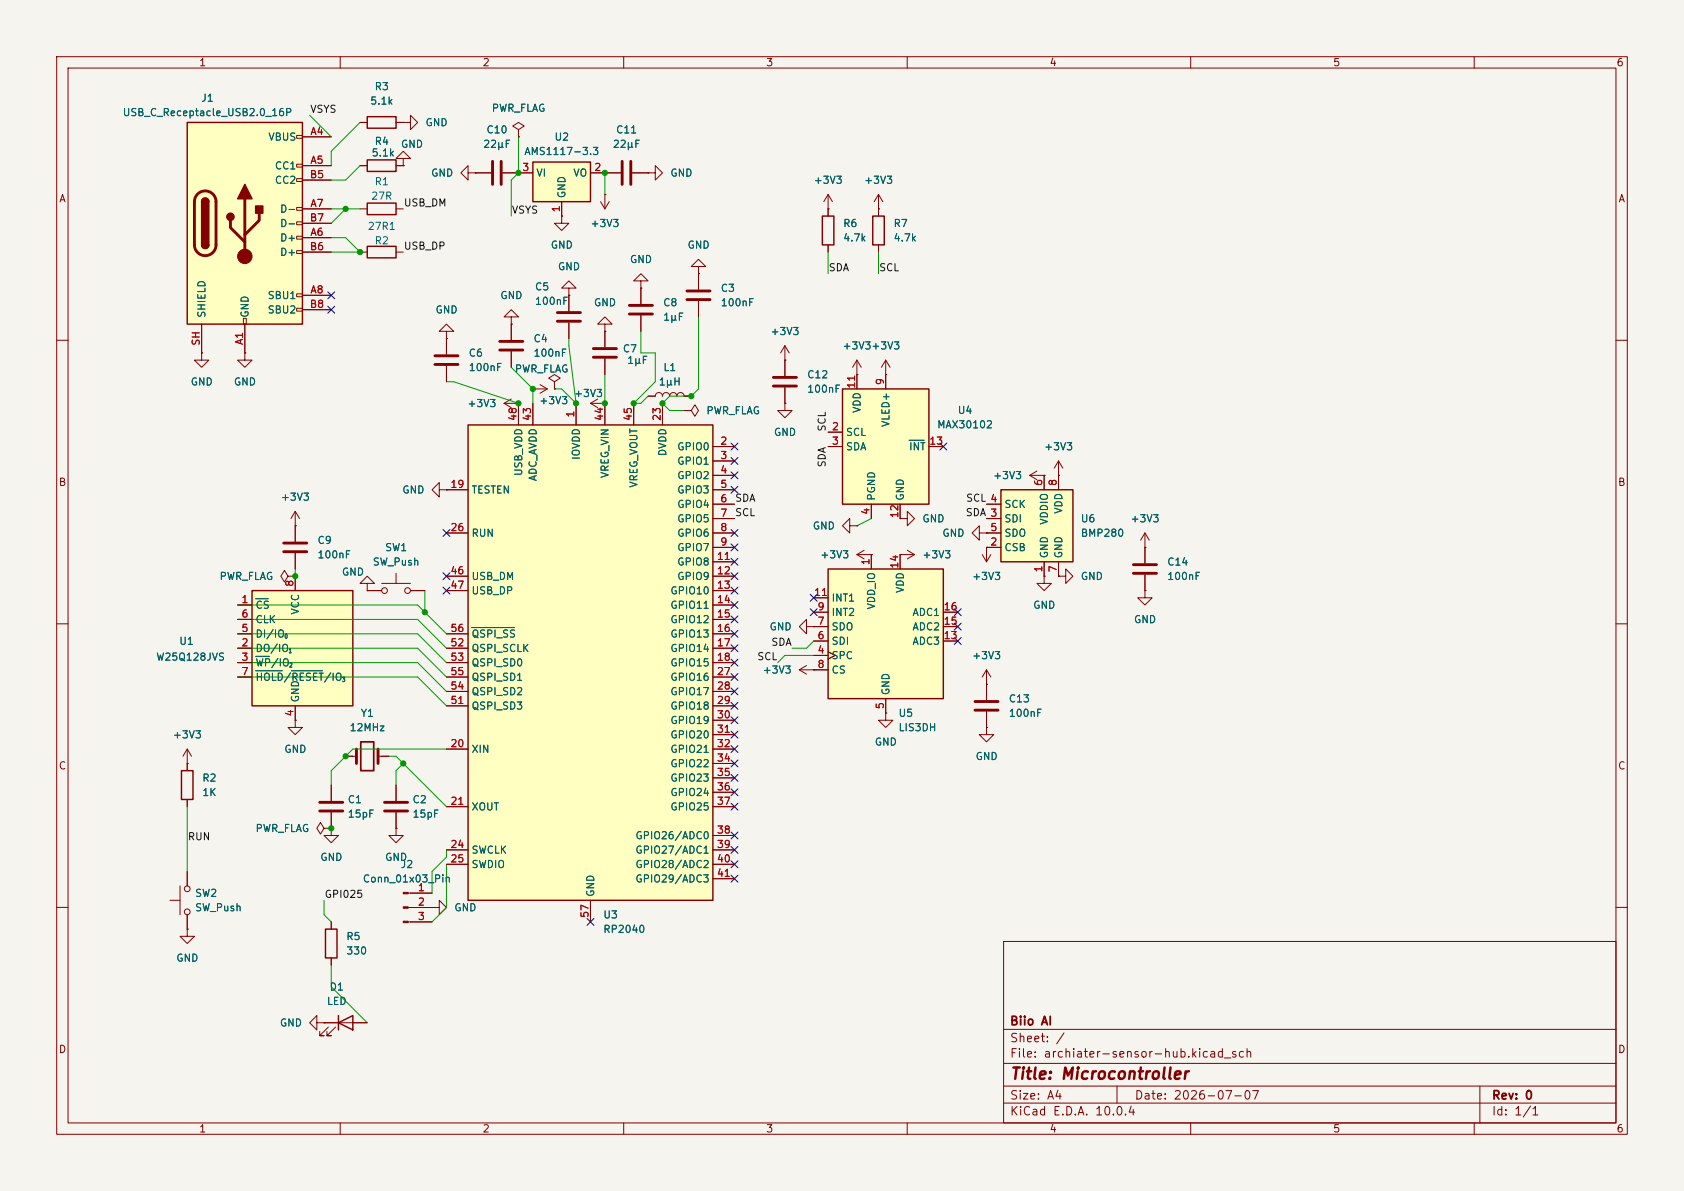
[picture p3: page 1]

Biio AI
Sheet: /
File: archiater-sensor-hub.kicad_sch
Title: Microcontroller

Size: A4 | Rev: 0
KiCad E.D.A. 10.0.4 | Id: 1/1

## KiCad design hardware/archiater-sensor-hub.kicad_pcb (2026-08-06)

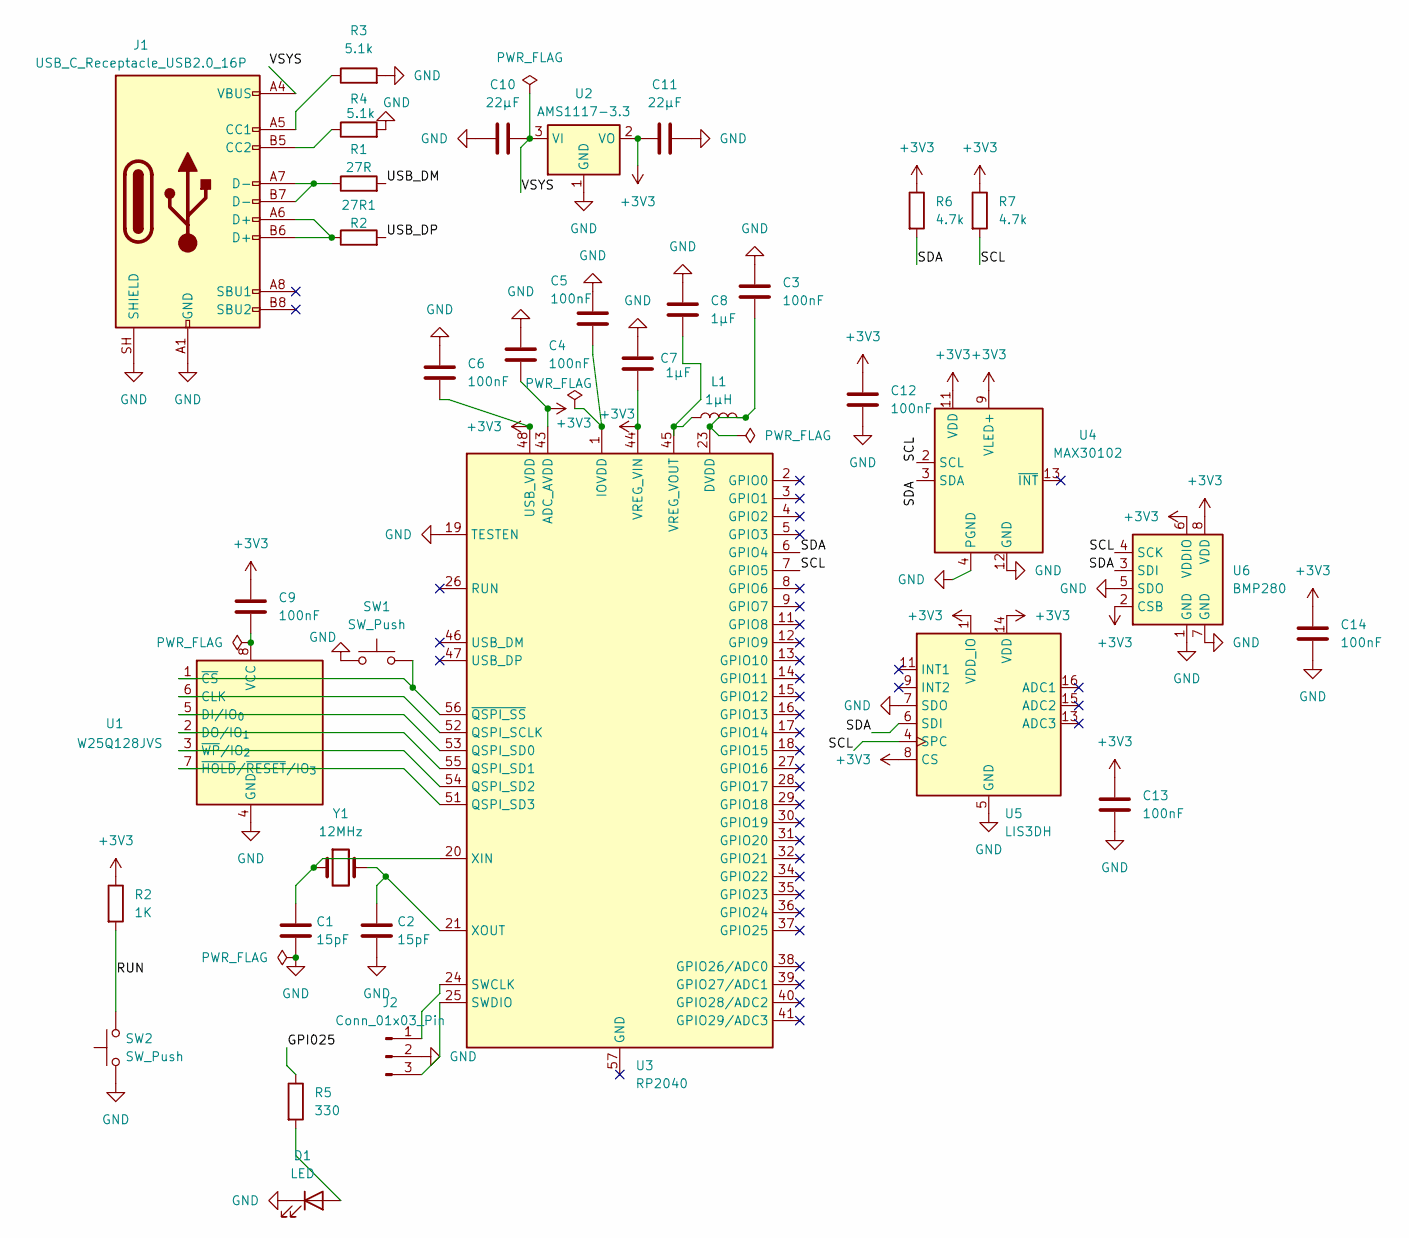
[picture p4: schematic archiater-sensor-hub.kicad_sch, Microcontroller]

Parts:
27R1: R2; R_0805_2012Metric
C1, C2: 15pF; C_0805_2012Metric
C3, C4, C5, C6, C9, C12, C13, C14: 100nF; C_0805_2012Metric
C7, C8: 1µF; C_0805_2012Metric
C10, C11: 22µF; C_0805_2012Metric
D1: LED; LED_0805_2012Metric
J1: USB_C_Receptacle_USB2.0_16P; USB_C_Receptacle_GCT_USB4105-xx-A_16P_TopMnt_Horizontal
J2: Conn_01x03_Pin; PinHeader_1x03_P2.54mm_Vertical
L1: 1µH; L_0805_2012Metric
R1: 27R; R_0805_2012Metric
R2: 1K; R_0805_2012Metric
R3, R4: 5.1k; R_0805_2012Metric
R5: 330; R_0805_2012Metric
R6, R7: 4.7k; R_0805_2012Metric
SW1, SW2: SW_Push; SW_SPST_TL3342
U1: W25Q128JVS; SOIC-8_5.3x5.3mm_P1.27mm
U2: AMS1117-3.3; SOT-223-3_TabPin2
U3: RP2040; QFN-56-1EP_7x7mm_P0.4mm_EP3.2x3.2mm
U4: MAX30102; Maxim_OLGA-14_3.3x5.6mm_P0.8mm
U5: LIS3DH; LGA-16_3x3mm_P0.5mm_LayoutBorder3x5y
U6: BMP280; Bosch_LGA-8_2x2.5mm_P0.65mm_ClockwisePinNumbering
Y1: 12MHz; Crystal_SMD_3215-2Pin_3.2x1.5mm

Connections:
+3V3: C4.2, C6.2, C7.2, C9.2, C11.2, C12.1, C13.1, C14.1, R2.1, R6.1, R7.1, U2.2 (VO), U3.43 (ADC_AVDD), U3.44 (VREG_VIN), U3.48 (USB_VDD), U4.9 (VLED+), U4.10 (VLED+), U4.11 (VDD), U5.1 (VDD_IO), U5.8 (CS), U5.14 (VDD), U6.2 (CSB), U6.6 (VDDIO), U6.8 (VDD)
/GPI025: R5.1
/RUN: R2.2, SW2.2
/SCL: R7.2, U3.7 (GPIO5), U4.2 (SCL), U5.4 (SPC), U6.4 (SCK)
/SDA: R6.2, U3.6 (GPIO4), U4.3 (SDA), U5.6 (SDI), U6.3 (SDI)
/USB_DM: R1.2
/USB_DP: 27R1.2
/VSYS: C10.1, J1.A4 (VBUS), J1.A9 (VBUS), J1.B4 (VBUS), J1.B9 (VBUS), U2.3 (VI)
GND: C1.2, C2.2, C3.1, C4.1, C5.1, C6.1, C7.1, C8.1, C10.2, C11.1, C12.2, C13.2, C14.2, D1.1 (K), J1.A1 (GND), J1.A12 (GND), J1.B1 (GND), J1.B12 (GND), J1.SH (SHIELD), J2.2, R3.2, R4.2, SW1.1, SW2.1, U1.4 (GND), U2.1 (GND), U3.19 (TESTEN), U4.4 (PGND), U4.12 (GND), U5.5 (GND), U5.7 (SDO), U5.10 (GND), U5.12 (GND), U6.1 (GND), U6.5 (SDO), U6.7 (GND)
unnamed: 27R1.1, J1.A6 (D+), J1.B6 (D+)
unnamed: C3.2, L1.2, U3.23 (DVDD), U3.50 (DVDD)
unnamed: C5.2, U3.1 (IOVDD), U3.10 (IOVDD), U3.22 (IOVDD), U3.33 (IOVDD), U3.42 (IOVDD), U3.49 (IOVDD)
unnamed: D1.2 (A), R5.2
unnamed: J1.A5 (CC1), R3.1
unnamed: J1.B5 (CC2), R4.1
unnamed: J1.A7 (D-), J1.B7 (D-), R1.1
unnamed: J2.1, U3.24 (SWCLK)
unnamed: J2.3, U3.25 (SWDIO)
unnamed: U1.6 (CLK), U3.52 (QSPI_SCLK)
unnamed: U1.5 (DI/IO_{0}), U3.53 (QSPI_SD0)
unnamed: U1.2 (DO/IO_{1}), U3.55 (QSPI_SD1)
unnamed: C9.1, U1.8 (VCC)
unnamed: SW1.2, U1.1 (~CS), U3.56 (~QSPI_SS)
unnamed: U1.7 (~HOLD/~RESET/IO_{3}), U3.51 (QSPI_SD3)
unnamed: U1.3 (~WP/IO_{2}), U3.54 (QSPI_SD2)
unnamed: C8.2, L1.1, U3.45 (VREG_VOUT)
unnamed: C1.1, U3.20 (XIN), Y1.1
unnamed: C2.1, U3.21 (XOUT), Y1.2

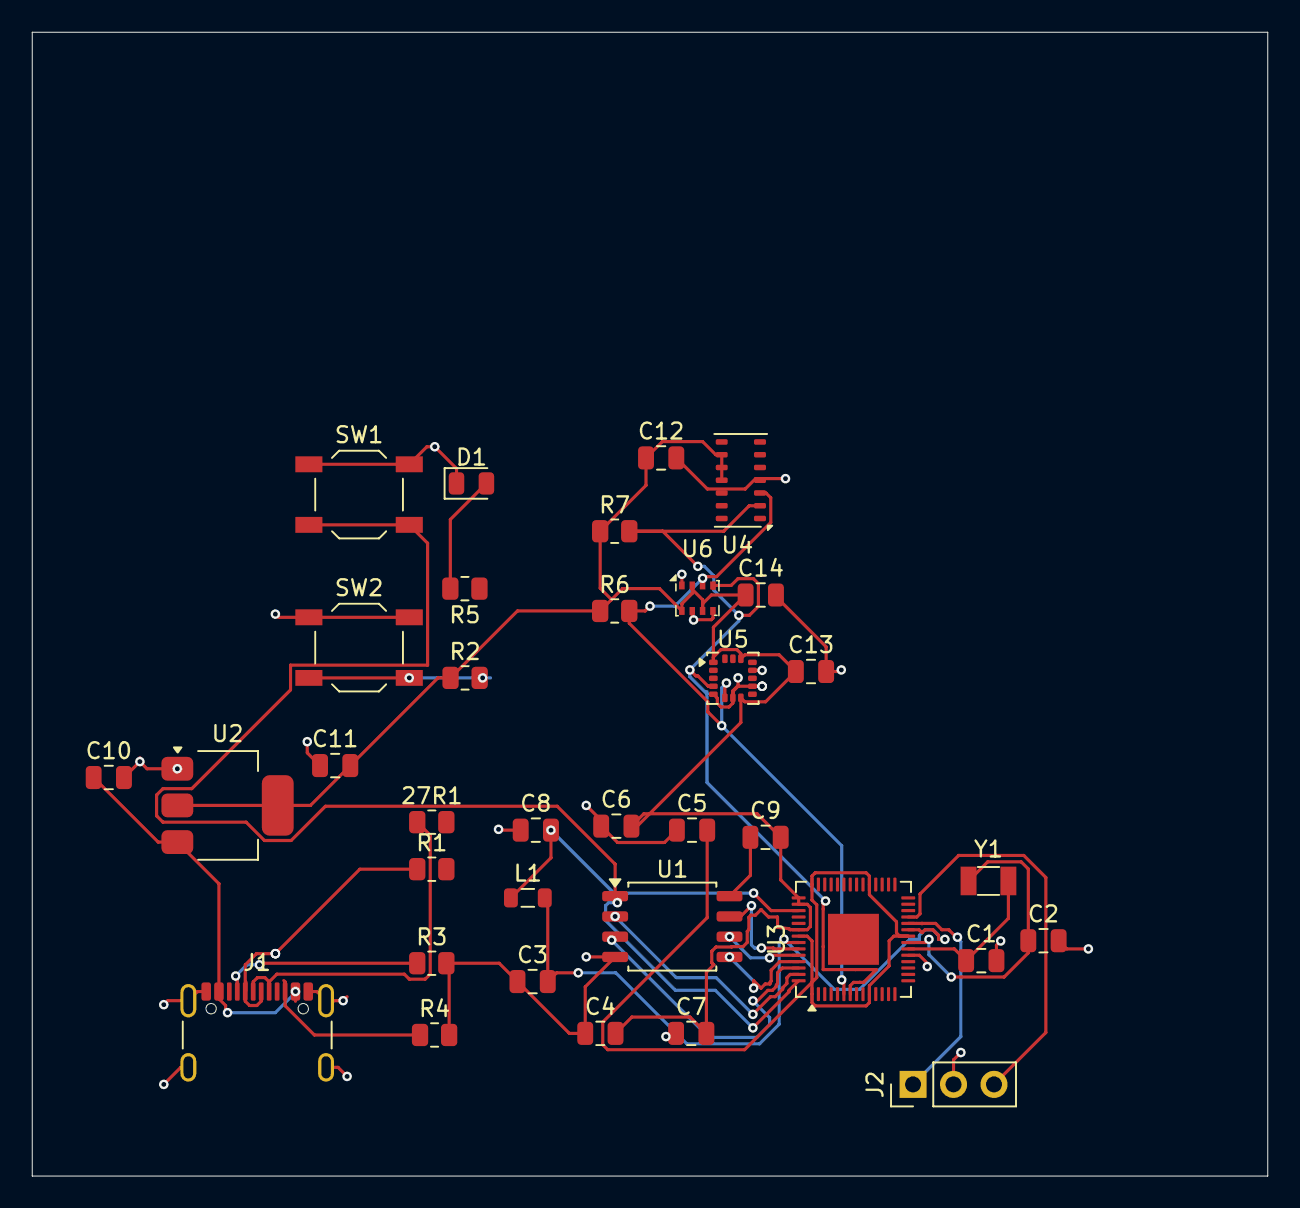
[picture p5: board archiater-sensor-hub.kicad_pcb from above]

Board: 2 copper layers, 77.5 x 71.8 mm, 35 parts (0 on the bottom side), 25 nets.

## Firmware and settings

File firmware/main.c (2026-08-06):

/*
 * main.c — Archiater sensor-hub firmware (breadboard prototype).
 *
 * Brings up the I2C bus and all three sensors, then loops every 100 ms:
 * reads each sensor, runs the fall-detection heuristic, and prints one JSON
 * object per line over USB serial. A downstream host (a small serial->WebSocket
 * bridge feeding the React Native app) consumes these lines.
 *
 * Bus: SDA = GPIO4, SCL = GPIO5, 400 kHz (fast mode).
 *   Why 400 kHz: all three sensors support fast mode; on short breadboard
 *   wiring there's no signal-integrity reason to run slower, and the higher
 *   rate leaves headroom for reading three devices inside each 100 ms tick.
 *   If wiring is long/noisy and reads fail, drop to 100 kHz (one constant).
 *
 * Output format (one line per tick), e.g.:
 *   {"t_ms":1234,"max30102":{"ok":true,"red":10342,"ir":10501},
 *    "bmp280":{"ok":true,"temp_c":22.5,"press_pa":101010.2,"alt_m":25.7},
 *    "lis3dh":{"ok":true,"x_g":0.01,"y_g":-0.02,"z_g":0.99,"mag_g":0.99},
 *    "fall_detected":false}
 *
 * UNTESTED ON HARDWARE — see README.md.
 */

#include <stdio.h>
#include "pico/stdlib.h"
#include "hardware/i2c.h"

#include "max30102.h"
#include "bmp280.h"
#include "lis3dh.h"

/* ---- Bus configuration -------------------------------------------------- */
#define I2C_PORT     i2c0
#define I2C_SDA_PIN  4          /* GPIO4 */
#define I2C_SCL_PIN  5          /* GPIO5 */
#define I2C_BAUD     400000     /* 400 kHz fast mode */

#define LOOP_PERIOD_MS 100      /* 10 Hz packaging loop */

static void i2c_bus_init(void) {
    i2c_init(I2C_PORT, I2C_BAUD);
    gpio_set_function(I2C_SDA_PIN, GPIO_FUNC_I2C);
    gpio_set_function(I2C_SCL_PIN, GPIO_FUNC_I2C);
    /*
     * Enable the RP2040's internal pull-ups as a fallback. On the real design
     * (and most breakout modules) there are stronger external 4.7k pull-ups;
     * the internal ones (~50k) are weak but prevent a fully floating bus if a
     * module lacks them. Harmless to have both.
     */
    gpio_pull_up(I2C_SDA_PIN);
    gpio_pull_up(I2C_SCL_PIN);
}

int main(void) {
    stdio_init_all();          /* USB serial (stdio over USB CDC) */

    /*
     * Give the USB CDC link a moment to enumerate so we don't drop the first
     * lines of output when viewing on a host terminal.
     */
    sleep_ms(2000);

    i2c_bus_init();

    /* Init each sensor; record which came up so we still stream the others. */
    bool max_ok = max30102_init(I2C_PORT);
    bmp280_calib_t bmp_calib;
    bool bmp_ok = bmp280_init(I2C_PORT, &bmp_calib);
    bool lis_ok = lis3dh_init(I2C_PORT);

    printf("{\"boot\":true,\"max30102_init\":%s,\"bmp280_init\":%s,"
           "\"lis3dh_init\":%s}\n",
           max_ok ? "true" : "false",
           bmp_ok ? "true" : "false",
           lis_ok ? "true" : "false");

    lis3dh_fall_state_t fall_state = {0};

    while (true) {
        uint32_t now = to_ms_since_boot(get_absolute_time());

        max30102_sample_t max_s = { .valid = false };
        bmp280_reading_t  bmp_r = { .valid = false };
        lis3dh_reading_t  lis_r = { .valid = false };

        if (max_ok) max30102_read(I2C_PORT, &max_s);
        if (bmp_ok) bmp280_read(I2C_PORT, &bmp_calib, &bmp_r);
        if (lis_ok) lis3dh_read(I2C_PORT, &lis_r);

        bool fall = false;
        if (lis_r.valid)
            fall = lis3dh_update_fall_detection(&fall_state, &lis_r, now);

        /* Emit one JSON line. Fields for failed reads report ok:false. */
        printf("{\"t_ms\":%lu,", (unsigned long)now);

        printf("\"max30102\":{\"ok\":%s", max_s.valid ? "true" : "false");
        if (max_s.valid)
            printf(",\"red\":%lu,\"ir\":%lu",
                   (unsigned long)max_s.red, (unsigned long)max_s.ir);
        printf("},");

        printf("\"bmp280\":{\"ok\":%s", bmp_r.valid ? "true" : "false");
        if (bmp_r.valid)
            printf(",\"temp_c\":%.2f,\"press_pa\":%.1f,\"alt_m\":%.1f",
                   bmp_r.temperature_c, bmp_r.pressure_pa, bmp_r.altitude_m);
        printf("},");

        printf("\"lis3dh\":{\"ok\":%s", lis_r.valid ? "true" : "false");
        if (lis_r.valid)
            printf(",\"x_g\":%.3f,\"y_g\":%.3f,\"z_g\":%.3f,\"mag_g\":%.3f",
                   lis_r.x_g, lis_r.y_g, lis_r.z_g, lis_r.magnitude_g);
        printf("},");

        printf("\"fall_detected\":%s}\n", fall ? "true" : "false");

        sleep_ms(LOOP_PERIOD_MS);
    }
    /* not reached */
    return 0;
}

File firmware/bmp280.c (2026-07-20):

/*
 * bmp280.c — Bosch BMP280 pressure/temperature driver.
 *
 * The compensation routines below are direct C transcriptions of the fixed-
 * point / floating-point reference formulas published in the BMP280 datasheet
 * (section 3.11.3, "Compensation formula"). The variable names (t_fine, var1,
 * var2, dig_*) are kept identical to Bosch's reference so a reviewer can diff
 * them against the datasheet line by line. We use the floating-point variant
 * for readability; Bosch also publishes a fixed-point variant.
 *
 * UNTESTED ON HARDWARE — see README.md.
 */

#include "bmp280.h"
#include "bmp280_compensation.h"   /* pure math: compensate_*, pressure_to_altitude */
#include "i2c_helpers.h"

/* ---- Register map (BMP280 datasheet, "Memory map" table) ---------------- */
#define REG_ID          0xD0  /* Chip ID register                            */
#define REG_RESET       0xE0  /* Soft reset                                  */
#define REG_CALIB_START 0x88  /* First byte of the 24-byte calibration block */
#define REG_CTRL_MEAS   0xF4  /* osrs_t, osrs_p, power mode                   */
#define REG_CONFIG      0xF5  /* standby time, IIR filter                     */
#define REG_PRESS_MSB   0xF7  /* First of 6 burst data bytes (press+temp)    */

/* The BMP280 reports this fixed chip id in REG_ID (0x58). Sanity check. */
#define BMP280_CHIP_ID 0x58

/*
 * CTRL_MEAS (0xF4) bit layout:
 *   [7:5] osrs_t — temperature oversampling. 0b001 = x1.
 *   [4:2] osrs_p — pressure oversampling.    0b011 = x4 (good pressure noise).
 *   [1:0] mode   — 0b11 = normal (continuous) mode.
 * (0b001<<5) | (0b011<<2) | 0b11 = 0x2F.
 */
#define CTRL_MEAS_NORMAL_T1_P4 0x2F

/*
 * CONFIG (0xF5):
 *   [7:5] t_sb   — standby between samples in normal mode. 0b000 = 0.5 ms.
 *   [4:2] filter — IIR filter coefficient. 0b100 = coeff 16 (smooths noise).
 *   [0]   spi3w_en — 0 (we're on I2C, not 3-wire SPI).
 * (0b000<<5) | (0b100<<2) | 0 = 0x10.
 */
#define CONFIG_TSB05_FILTER16 0x10

/* Read a little-endian unsigned 16-bit value from two consecutive cal bytes. */
static uint16_t le16u(const uint8_t *p) {
    return (uint16_t)(p[0] | (p[1] << 8));
}
static int16_t le16s(const uint8_t *p) {
    return (int16_t)(p[0] | (p[1] << 8));
}

bool bmp280_init(i2c_inst_t *i2c, bmp280_calib_t *calib_out) {
    uint8_t id = 0;
    if (i2c_read_reg(i2c, BMP280_ADDR, REG_ID, &id) < 0) return false;
    if (id != BMP280_CHIP_ID) return false;

    /* Read the 24-byte factory calibration block (0x88..0x9F) in one burst. */
    uint8_t c[24];
    if (i2c_read_regs(i2c, BMP280_ADDR, REG_CALIB_START, c, 24) < 0)
        return false;

    /* Unpack per the datasheet's field order and signedness. */
    calib_out->dig_T1 = le16u(&c[0]);
    calib_out->dig_T2 = le16s(&c[2]);
    calib_out->dig_T3 = le16s(&c[4]);
    calib_out->dig_P1 = le16u(&c[6]);
    calib_out->dig_P2 = le16s(&c[8]);
    calib_out->dig_P3 = le16s(&c[10]);
    calib_out->dig_P4 = le16s(&c[12]);
    calib_out->dig_P5 = le16s(&c[14]);
    calib_out->dig_P6 = le16s(&c[16]);
    calib_out->dig_P7 = le16s(&c[18]);
    calib_out->dig_P8 = le16s(&c[20]);
    calib_out->dig_P9 = le16s(&c[22]);

    /* Configure filter first, then measurement mode (datasheet ordering). */
    if (i2c_write_reg(i2c, BMP280_ADDR, REG_CONFIG, CONFIG_TSB05_FILTER16) < 0)
        return false;
    if (i2c_write_reg(i2c, BMP280_ADDR, REG_CTRL_MEAS, CTRL_MEAS_NORMAL_T1_P4) < 0)
        return false;

    return true;
}

/*
 * NOTE: the Bosch floating-point compensation math (temperature + pressure)
 * and the barometric altitude formula used to live here as static functions.
 * They now live in bmp280_compensation.c as pure, hardware-free functions so
 * they can be unit-tested on a host machine. This driver reads the raw bytes
 * and calls those functions; the arithmetic is unchanged.
 */

bool bmp280_read(i2c_inst_t *i2c, const bmp280_calib_t *calib,
                 bmp280_reading_t *out) {
    out->valid = false;

    /*
     * Burst-read 6 bytes starting at PRESS_MSB (0xF7):
     *   press[19:12], press[11:4], press[3:0]<<4,
     *   temp[19:12],  temp[11:4],  temp[3:0]<<4.
     * Each of pressure and temperature is a 20-bit value.
     */
    uint8_t d[6];
    if (i2c_read_regs(i2c, BMP280_ADDR, REG_PRESS_MSB, d, 6) < 0)
        return false;

    int32_t adc_P = ((int32_t)d[0] << 12) | ((int32_t)d[1] << 4) | (d[2] >> 4);
    int32_t adc_T = ((int32_t)d[3] << 12) | ((int32_t)d[4] << 4) | (d[5] >> 4);

    float t_fine;
    out->temperature_c = bmp280_compensate_temperature(calib, adc_T, &t_fine);
    out->pressure_pa   = bmp280_compensate_pressure(calib, adc_P, t_fine);
    out->altitude_m    = bmp280_pressure_to_altitude(out->pressure_pa);

    out->valid = true;
    return true;
}

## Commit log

2026-05-26 Initial Ghost Medic skeleton — offline TCCC trauma assistant
    - 3-screen flow: Boot → Triage → Action
    - MARCH protocol decision engine (TCCC v5)
    - Live bracelet vitals mock (HR, SpO2, sBP, temp, shock index)
    - Wound photo capture + voice recording input
    - Silent / buddy-aid / self-aid modes
    - SDK 54 / React Native 0.81 / React 19
    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
2026-06-25 Rebuild UI as single-file 3-state machine
    Replace the multi-screen flow (triage/vitals/action/evacuation/handoff)
    with one app/index.tsx state machine: READY → THINKING → RESPONSE.
    - READY: hold-to-speak circle, photo picker, inline text input, audio toggle
    - THINKING: pulsing dot, cancellable LLM call (AbortSignal)
    - RESPONSE: numbered steps + amber evacuation box, step-by-step read-aloud
    Update system prompt in llmService to solo-backcountry survival focus and
    add streamTCCCGuidance with cancellation. Add services/transcriptionService
    stub. Recording uses expo-audio (SDK 54); add expo-speech for TTS.
2026-06-30 Fix keyboard dismissal, use real camera, add image-context review step
    - Wrap screen in Pressable+KeyboardAvoidingView with a DONE button so the
    keyboard can always be dismissed when typing
    - PHOTOGRAPH WOUND now opens the camera (launchCameraAsync) with a permission
    check, capturing base64 for the LLM payload
    - Add an intermediate REVIEW state to attach a textual description to the
    captured image before sending the casualty report
2026-07-19 Add wrist-unit sensor firmware (RP2040) as monorepo firmware/
    Bring the Ghost Medic sensor hub firmware into the repo alongside the
    React Native app so the whole system lives in one place.
    - firmware/: bare-metal C for a Raspberry Pi Pico reading MAX30102,
    BMP280, and LIS3DH over a shared I2C bus, streaming JSON over USB serial
    - firmware/.gitignore: scoped Pico SDK / CMake ignores; keeps the
    prebuilt ghost_medic_firmware.uf2 tracked as compile proof
    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
2026-07-19 firmware: enforce -Wall -Wextra -O3 on the target in CMakeLists
    The README claimed a zero-warning build under -Wall -Wextra at -O3, but the
    build config didn't actually set those flags — a plain `cmake && make` used
    SDK defaults. Add them scoped to the ghost_medic_firmware target (PRIVATE) so
    the claim is enforced by the build itself, without clobbering the SDK's
    -mcpu/-mthumb arch flags.
    Verified by building from source against the Pico SDK with arm-none-eabi-gcc
    13.3.1: clean compile, zero warnings/errors on all four sources, valid UF2.
2026-07-20 Refactor sensor math into testable pure modules + add host-side tests
    Split the BMP280 compensation math and the LIS3DH fall-detection state
    machine out of the hardware drivers into pure, hardware-free modules
    (bmp280_compensation.{h,c}, fall_detection.{h,c}) so they can be unit-
    tested on a host with plain gcc. The drivers still do all I2C reads and
    byte-unpacking, then call the pure functions; the arithmetic is byte-for-
    byte unchanged and firmware behavior is identical.
    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
2026-07-21 Archive TCCC deterministic engine to legacy/; single-product structure
    Decision (2026-07-20): the product is the LLM wilderness assistant (app/ +
    services/). The repo had drifted into two products; the older deterministic
    TCCC/MARCH engine + its 9-screen flow are moved to legacy/ so the active tree
    contains one product only.
    - Move App.js + all of src/ (screens, tccc engine, store, scenarios, components,
    theme, context, hooks, data, types) -> legacy/ via git mv (history preserved).
    - Rescue the forward-looking sensor/vision stubs up to services/ (roadmap Phase
    1-2 scaffolding, not TCCC): biosensorService.ts, visionService.ts.
    - Drop the now-dangling '@' -> ./src alias from babel + tscon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
2026-07-21 Add ROADMAP, ARCHITECTURE, DATA_FORMAT; point README at them
    Project memory so no session has to hold the whole project in its head:
    - ROADMAP.md: phased plan (Phase 0 done, bridge is Phase 1) with definition-of-
    done per phase, a deferred/anti-rathole list, and the optimize-for-proof framing.
    - ARCHITECTURE.md: system topology (biosensor/wearable/pack/interface), what runs
    where today vs. shipping, and an explicit real-vs-simulated table.
    - DATA_FORMAT.md: the NDJSON wire contract (verified against firmware/main.c),
    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
2026-07-21 Enable Expo web export: add react-native-web + worklets, align react-dom
    De-risks the load-bearing assumption for the final Vercel deliverable: can the
    Expo app (app/index.tsx) become a static website? YES — verified below.
    Changes:
    - add react-native-web@0.21.2 (renders React Native on the web)
    - add react-native-worklets@0.11.1 (Reanimated 4 split worklets into this pkg;
    the babel reanimated/plugin requires it)
    - align react-dom 19.1.0 to match react 19.1.0 (they were skewed: react-dom had
    drifted to 19.2.x, which blocked the export)
    Verified: `npx expo export --platform web` succeeds -> dist/index.html + a
    2.04 MB JS bundle; bundle passes `node --check`; static-served returns HTTP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
2026-07-21 Honesty fix: correct MAX30102 labeling to raw optical, rename trauma→first-aid assistant
2026-07-21 Wire app to bridge vitals; update roadmap with locked decisions
    - app/index.tsx: useWristVitals() at top level, VitalsMonitor on READY screen
    (●LIVE/○DISCONNECTED indicator, DERIVED alt/temp/fall + RAW optical/accel,
    nulls render '—', no HR/SpO2). Verified: tsc clean; compiled parser maps the
    live bridge stream to correct values incl. ok:false -> '—'.
    - ROADMAP.md: bridge + app-wiring marked DONE in Phase 1; added Locked Decisions
    section (the 4 committed decisions + out-of-scope list) near the top.
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2026-07-22 Add wrist-unit KiCad PCB source (hardware/); back the 'PCB designed' claim
    - hardware/: real KiCad 10.x source (schematic + routed board + project),
    exported schematic PDF + 3D render (regenerable via kicad-cli), and a README
    stating the honest status: designed & routed, NOT fabricated/assembled/tested.
    - MAX30102 labeled raw optical (PPG), consistent with the honesty pass.
    - ARCHITECTURE.md real-vs-simulated row now points at hardware/ (was the one
    unbacked claim); WEBSITE_STRATEGY.md §0 PCB risk marked resolved.
    [ghostmedic-sensor-hub.kicad_pcb, ghostmedic-sensor-hub.kicad_sch]
2026-07-22 Phase 2: sensor-context builder + sensor-aware system prompt
    - services/sensorContext.ts: pure WristVitals -> delimited text block. Gates
    every field on ok/null ('unavailable', never 0), qualifies altitude as
    relative/pressure-derived and temp as ambient-not-body, states that raw
    optical counts carry no HR/SpO2. Headless tests: 16/16 pass.
    - llmService.ts system prompt: extends (not replaces) wilderness framing with
    rules for reasoning about sensor context — incl. NEVER inferring heart rate
    or SpO2 from raw counts, and user report winning over sensors.
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2026-07-22 Simulator: temp-offset + per-sensor failure controls; remove bpm display
    - New TEMP OFFSET slider (-40..+20 °C on top of altitude lapse) for cold-snap
    demos; new per-sensor failure checkboxes emitting {"ok":false} with fields
    OMITTED per DATA_FORMAT.md — exercises the app's ok:false path end-to-end.
    - Honesty fix (Decision 2): the exertion control and MAX30102 tile no longer
    display 'heart rate N bpm' — the pulse model is renamed exertionToPulseDriver,
    internal-only, never displayed or emitted; tile now shows raw IR counts.
    - Failed sensors show em-dash tiles, never 0; LIS3DH failure disables fall
    detection for that tick (no reading -> no detection).
    - Standalone gating untouc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
2026-07-22 Honesty sweep: purge remaining HR/SpO2/trauma overclaims; add CLAUDE.md
    - DELETE services/biosensorService.ts (fabricated HR/SpO2/BP stub; imported by
    nothing — replaced by useWristVitals per Phase 1). Recoverable from history.
    - firmware/README.md sensor table: MAX30102 role -> 'Raw optical (PPG)
    front-end' (was 'Heart rate / SpO2 (raw)').
    - simulator/README.md: controls section matches new simulator — pulse model
    internal-only, temp offset + sensor-failure toggles documented.
    - visionService.ts stub prompt: trauma/combat-medic -> wilderness first-aid.
    - WEBSITE_STRATEGY.md hero copy: trauma assistant -> first-aid assistant
    prototype.
    - llmService.ts: explicit comments that disp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
2026-07-22 Commit the TypeScript tests the docs already claimed (39, zero deps)
    ROADMAP.md and the site claimed sensorContext 16/16 and fallTrigger 6/6.
    Those numbers came from throwaway in-session harnesses that were never
    committed, so a reviewer who clicked through to verify found nothing —
    the same failure mode as the phantom transcript caught in the Phase 4
    audit. This makes the claim checkable.
    npm test -> 39 tests, 39 pass
    wristVitalsParser 11 reading one telemetry line (the ok:false trap)
    sensorContext 16 the block the model is given
    fallTrigger 12 one question per fall, not one per reading
    No framework and no new dependency: node:test plus Node's native
    TypeS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
2026-07-22 Chart pipeline: three plates drawn from the shipping code's own output
    The site claimed the maths and the debounce in prose. Now it shows them,
    and the data is generated by the code under discussion rather than a
    reimplementation:
    - fall-signature.svg trace_driver.c links the firmware's own
    fall_detection.c; the motion trace is synthetic
    and labelled so, every flag decision is the real
    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
    [altitude_curve.csv, debounce.csv, fall_trace.csv]
2026-07-22 Add a 3D product concept and a scripted interface demo
    The site explained the system but never showed it. Two additions,
    both labelled for exactly what they are.
    PRODUCT CONCEPT (site/assets/product-viewer.js, on the overview page)
    A wrist unit wired to a belt pack, built as placeholder shapes in code.
    Not CAD, no design file behind it, and the page says so directly. This
    overrides the earlier rule against concept renders; the owner asked for
    it, and the honesty cost is paid with labels rather than by omission.
    Geometry worth noting, since a first pass got these wrong:
    - The band is an open 300-degree arc with a rectangular cross-section
    swept along it, tapering toward the ends, not a t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
2026-07-22 Wire in the new pieces, layer the background, tighten the prose
    Site changes:
    - Overview gains the product concept section; How it works gains the
    altitude and fall-signature charts plus the interface demo; Proof
    gains the debounce chart and the concept-display ledger row.
    - Background is layered rather than flat: soft sand and pale-green
    washes down the page so a long scroll alternates warm and cool. Text
    surfaces are untouched, so contrast is unchanged.
    - Prose tightened across all four pages toward roughly a minute of
    reading each. Cut the "not X, not Y, but Z" constructions and the
    paragraphs that restated a point already made by an adjacent chart or
    label.
    - Stylesheet lin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
2026-07-22 Refine the concept illustration, add an About page, cut more prose
    CONCEPT ILLUSTRATION (targeted fixes, composition unchanged)
    - Cable tube radius 1.1 -> 3.0, so it reads as a cable rather than a
    filament. Same catenary slack, same endpoints. Both connector bosses
    scaled to match.
    - Belt pack reads as a moulded enclosure rather than an extruded slab:
    a parting seam running around it at mid-thickness, a recessed
    connector well with a metal collar where the cable lands, five vent
    slots instead of three, and larger fillets. Size, position, curved
    inner face and belt interface all unchanged.
    - Display 34x42 -> 37x44 on the same 40x48 case, so it grows about 14%
    and the bezel drop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
2026-07-22 Fix concept scale and belt strap; tighten Hardware and Proof; About me
    SCALE. The pack was rendering 136 mm wide, 2.84x the wrist case, which
    read as luggage. Root cause found by measuring the rendered bounding
    boxes rather than eyeballing: bendAroundY computed the arc angle at the
    150 mm body radius but placed vertices out to 175, stretching the outer
    face 17%. Bending at the outer radius instead preserves the documented
    120 mm and lands the largest-face ratio at 2.45x the case's 48 mm edge,
    against the ~2.5 target. Wrist case (48x40x11) and pack (120x80x25)
    dimensions are unchanged; only the render matches them now.
    BELT STRAP. Was a flat panel off one edge. Rebuilt as a rectangular
    cross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
2026-07-23 Concept: per-vertex bend, deeper cable, more enclosure detail
    bendAroundY now takes each vertex's own radius (theta = x / r) rather
    than a single fixed radius. The fixed-radius bend held the pack's outer
    face right but squeezed the inner face into a wedge (92 mm vs 107 mm);
    the per-vertex bend renders 117 mm across with inner and outer within a
    millimetre, verified headless against the real RoundedBoxGeometry.
    Cable deepened into a catenary (54% slack vs the straight span, clears
    the floor). Wrist detail: two side buttons (the board's real SW1/SW2 —
    not a crown, which would imply an encoder the board lacks), an underside
    optical aperture (the MAX30102 window), strap lugs. Pack detail: a
    r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
2026-07-23 Cut the site prose, keeping every disclosure and evidence link
    Aggressive prose pass across all five pages so a reader flips through in
    about a minute and the artifacts carry the weight. Total prose ~3446 ->
    ~2749 words; body prose (excl. tables/ledger/chrome) ~2637 -> ~2027.
    Cut motivation and narrative between artifacts, compressed multi-sentence
    explanations to single sentences, turned the no-heart-rate enforcement
    into an actual list, dropped captions that only restated a diagram's own
    labels, and compressed the footer disclaimer. Kept every honesty
    disclosure (shortened, never removed): the concept-display note, the
    "no module selected / nothing measured" note, the render's two gaps, t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
2026-07-25 Put the concept on a body, and build a way to actually see the render
    Every earlier concept session verified geometry by measuring bounding boxes,
    because no browser was installed here. tools/render/ fixes that: preview.html
    mounts the viewer on its own with the camera the site ships, and shot.mjs
    screenshots it over the Chrome DevTools Protocol. No new dependency — Node's
    built-in WebSocket drives a Chromium already on the machine.
    It paid for itself twice. The band was mounting itself from the straight
    elbow-to-wrist chord instead of the curve's tangent, so it sat skewed over the
    base of the hand. And the cable ran from the connector straight at the belt,
    which on a raised arm means thr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
2026-07-25 Docs: record Phase 4d, and that the simulator is standalone now
    ROADMAP gets the Phase 4d entry, including the part that reflects badly: the
    first diagnosis of the misplaced wrist band blamed centripetal Catmull-Rom
    spacing, which was wrong. three.js maps t uniformly across segments, so the
    original table was fine and the real cause was the mount axis. The comment in
    wearer-figure.js says the same rather than keeping the tidier story.
    The known-cleanups note about keeping site/simulator/index.html in sync is
    struck through, and ARCHITECTURE's "three data sources" no longer calls the
    simulator a demo for the website, because it is not embedded anywhere now.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
2026-08-06 Docs+site: the story catches up with the decision
    Three-box topology (wrist sensor accessory, the link, the end-user device)
    replaces the four-role diagram; the pack-compute question is closed, not
    deferred. ROADMAP gains a superseding decision block and Phase 5; CLAUDE.md
    gains the posture rule. Site: only the claims the repositioning falsified
    are touched (pack computer wording, the killed-computer ledger row); the
    full text rewrite is a later session.
    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
2026-08-06 Rename, step 6 of 6: KiCad sources, exports, and site assets
    The three KiCad sources move to archiater-sensor-hub.* with their internal
    sheetfile/project references updated; all 129 internal hits were quoted
    values, verified before the edit. All four exports regenerated from the
    renamed source with kicad-cli 10 (byte sizes within a few bytes of the old
    ones), copied to site/assets, and every referencing path updated. Verified
    by screenshot: the hardware page loads and renders the renamed GLB.
    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
    [archiater-sensor-hub.kicad_pcb, archiater-sensor-hub.kicad_sch]
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2026-08-06 Site: the oasis, as scenery that never makes a claim
    Dune, pool, water and frond tokens join the palette as decoration only;
    forest stays the working ink and clay stays reserved for stand-ins, and the
    stylesheet says so. An inline-SVG oasis hero on the overview, a dune-ribbon
    divider under each interior nav, a dusk waterline above every footer, paper
    grain from a build-time PNG tile, and depth shadows that set the evidence
    plates on the sand. Zero text nodes changed: the readability output is
    byte-identical before and after. Also fixes a real accessibility miss,
    --ink-3 at 2.9:1, now 5.2:1.
    The grain tile ships as a plain asset with its generator committed: an SVG
    filter background stalled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
2026-08-06 Figure: male, and the phone carried at the hip pocket
    apply-target.mjs applies MakeHuman's CC0 macrodetail morph, so the mannequin
    is now the male corner of the same base mesh, through the same pipeline. The
    end-user device moves from a chest rig to a low belt at the hip, where a
    pocket sits and where a hanging wrist ends up, which also shortens the
    cable. The carry frame is read off the measured hip surface; the phone
    preset looks down that frame's own normal.
    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
2026-08-06 Site: a living oasis, two tabs, and another fluff cut
    The hero is a canvas scene now: layered dunes, palms whose fronds sway on
    their own phases, a pool with a wavering reflection, sand drifting off the
    crests, and a passing shower that rings the water where drops land. Colours
    come from the stylesheet's scenery tokens; reduced motion gets one still
    frame; the inline SVG remains for no-JavaScript visitors. The 3D viewer is
    two tabs, On the body and Devices. Body prose cut again on all four content
    pages (index 395 words, how-it-works 533, hardware 513, proof 802), every
    honesty device kept; readability, links, tests, and the external-request
    grep all re-run green.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
2026-08-06 Positioning: the phone is enough, verified
    The on-device claim is now a checked fact with named sources: Apple ships a
    3B-parameter model on iPhone 15 Pro and later at about 30 tokens a second,
    Google ships Gemini Nano through AICore, and quantized Llama 3.2 3B decodes
    at about 22 tokens a second on an iPhone 16 Pro in roughly 2.8 GB. The
    honest limits are recorded too: thermal decay under sustained load, short
    context, and small models being fit for retrieval-shaped support rather
    than open-ended clinical reasoning, which is exactly the posture this
    product takes.
    Claude-Session: https://claude.ai/code/session_01BLoHmdMMczf75ok2GCS4Zg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
2026-08-06 Oasis: the grove, and rain that stays
    Lush broadleaf trees now frame the headline: each is hundreds of leaf blobs
    pre-rendered once to an offscreen sprite, drawn per frame with a slow sway
    at the trunk, so the canopy is dense and the frame cost is a handful of
    draws. Understory shrubs anchor the corners and sink into the fade; two
    bushes sit on the pool bank. The rain is no longer a rare pass: a soft
    drizzle is always falling and swells in long waves, ringing the pool where
    drops land. Reduced motion still gets one dry, still frame.
    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
2026-08-06 Verge: foliage down the margins of every page
    Two fixed strips flank the viewport, sized to the free margin beside the
    content column and gone entirely when it is thin. Ferns, vines and leafy
    sprigs reach in from the edges as pre-rendered sprites, sway on their own
    phases, drift gently against the scroll, and share the hero's soft rain.
    The greenery frames the text everywhere without ever sitting under it.
    shot.mjs takes a scrollY argument now, because a fixed layer cannot be
    photographed mid-page any other way.
    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
2026-08-07 Figure: the hands were in the hip measurements
    An A-pose hangs the hands at exactly the heights where the belt and the
    carry mount are measured, and their vertices leaked into the radial torso
    profile: the belt ballooned outward and the phone seated on the hand
    instead of the hip, which the owner caught on the live site. The profile
    now excludes anything wider than the pelvis through that band of heights,
    extends the arm-axis exclusion to cover the hands, and runs a circular
    median over each row so any surviving spike dies without rounding the true
    surface. Verified by preview screenshots: the belt is snug and the phone
    sits flush below it.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
2026-08-07 Verge: the washes that were never there, painted where paint survives
    The stylesheet's body background was committed truncated: the declaration
    listed two of its seven layers and ran straight into background-repeat,
    which makes the whole declaration invalid CSS — so every page silently
    dropped ALL of it, washes and grain alike, and rendered plain stone. The
    owner saw the flat page and asked where the greenery went. It had never
    shipped.
    The washes cannot go back as background layers: any body background-image
    with a page-scale destination — a stretched bitmap, a radial-gradient
    stack, any attachment or repeat — stalls software rasterisers at
    screenshot time on every long page (verifie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
2026-08-07 Figure: the phone hangs from the belt, hooked over it
    The owner's screenshot showed the pre-fix render (a stale cached
    wearer-figure.js: ballooned belt, phone out at the hand — the exact bug
    28f3793 fixed), but the current carry had its own tell: the phone's top
    edge reached 2 mm shy of the belt's top, so the device covered the whole
    band at its station and read as a slab floating on the hip.
    Now the carry is an explicit holster. The phone's centre height is chosen
    so its top edge lands on the belt's centreline, leaving the band's upper
    half visible above the device; the hip plate deepens to fill the air gap
    to the body and stops under the band instead of poking through it; and a
    hook str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
2026-08-07 Figure: the body axis was outside the body
    The owner rotated the live viewer overhead and caught the phone hovering
    in open space off the hip — attached-looking from the front, floating
    from above. The root cause ran deeper than the carry: the mesh is centred
    by whole-body bounding box, and the A-pose arms tilt far enough forward
    that the box centre — the x = z = 0 axis every radial measurement trusts
    — sat OUTSIDE the trunk at hip height. Histogramming vertex bearings in
    the carry band proved it: the entire front half of the profile had no
    vertices, and gap-fill had been quietly inventing front radii from arm
    bins. The belt only ever looked right by luck of the fill.
    Fixes, each veri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
